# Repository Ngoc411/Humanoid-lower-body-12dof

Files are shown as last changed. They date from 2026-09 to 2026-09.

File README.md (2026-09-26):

<div align="center">
  
  <br>
  <em>Chaos — a 12-DoF humanoid lower-body robot, sim-to-real RL locomotion</em>
</div>

# Humanoid-lower-body-12dof (Chaos)

This repository holds the full stack for **Chaos**, a 12-degree-of-freedom humanoid
lower-body robot (6 DoF per leg: hip yaw / hip roll / hip pitch / knee / ankle pitch /
ankle roll): reinforcement-learning training in simulation, the ONNX policy runtime,
and the embedded firmware that runs on the physical robot.

> **Acknowledgement / reference:** the simulation and RL training pipeline in this
> repo is built on top of, and takes reference from,
> **[VinRobotics/vinrobotics_mjlab](https://github.com/VinRobotics/vinrobotics_mjlab)**.
> Credit to that project and its authors for the base framework this work extends.

## Project layout

```
.
├── source/Vin_Rsl_Rl/          # Isaac Lab-style RL extension (Python package "Vin_Rsl_Rl")
│   └── Vin_Rsl_Rl/
│       ├── assets/robots/      # Robot articulation config ("chaos.py": joints, actuators, PD gains)
│       └── tasks/              # Gym-style task definitions (manager-based & direct)
│           ├── manager_based/vin_rsl_rl/   # MDP: rewards, terminations, curriculum, observations
│           └── direct/                     # Direct-workflow + multi-agent (MARL) variants
├── scripts/                    # Train / play entry points for each RL library
│   ├── rsl_rl/                 # train.py, play.py, plot_policy_data.py (primary pipeline)
│   ├── rl_games/                # train.py, play.py
│   ├── sb3/                    # train.py, play.py
│   └── skrl/                    # train.py, play.py
├── step_response_data/         # Real-motor step-response / wave-motion logs used to fit
│                                # simulated actuator dynamics (armature, friction, viscous
│                                # friction) per joint against the physical robot
├── ws1_cpp/ws1_cpp/             # ROS 2 C++ workspace that runs on the Jetson (deploys the
│   ├── sensor_node/             #   trained ONNX policy on hardware)
│   ├── src/                     # sensor_node : SPI master, reads 46-float obs frame from STM32
│   ├── action_node/             # main_node   : runs actor.onnx, fall/recovery state machine
│   └── test_model_node/         # action_node : writes the 12-joint action frame back to STM32
│                                 # test_model_node : offline CLI sanity check of the ONNX model
├── Chaos_main_1/                # STM32F407VET6 firmware — main board / SPI slave to the
│                                 # Jetson, CAN master to the 12 per-joint motor nodes
│   ├── NODE_FLOW.md             # Full node/data-flow reference for the STM↔Jetson link
│   ├── JETSON_NOTES.txt         # Fall-detection & recovery handshake, data-safety checklist
│   └── STM32_SAFETY_SUMMARY.txt # NaN/CRC/framing/watchdog protections on the STM32 side
├── Chaos_test3/                  # STM32G474 firmware flashed to each of the 12 joint nodes
│                                 # (one CAN node per motor; NODE_ID selects which joint)
├── Hardware/                      # Mechanical CAD (SolidWorks) for the physical robot
│   ├── hip_2/hip_3/hip_connector, knee_1/2_left/right, ankle*  # Structural leg parts
│   ├── gearbox/                   # Custom planetary gearboxes for the BLDC actuators
│   │   ├── gearbox_5210/          #   (5210-size motor)
│   │   └── gearbox_3508/, gearbox_3508_2/  # (3508-size motor, two revisions)
│   ├── BLDC/                      # Motor mount parts for the 5210 / 3508 / 4108 BLDC motors
│   ├── bearing/                   # Bearing mounts
│   ├── assem_symplified.SLDASM    # Full simplified leg/body assembly
│   └── Jetson Nano.step           # Reference model for mounting the onboard computer
├── test7.usd                      # Isaac Sim USD asset for Chaos, referenced as
│                                  # `usd_path` in `source/.../assets/robots/chaos.py`
└── flat_ter.gif / flat_ter.mov   # Walking demo captured from simulation
```

## System overview

Chaos is trained to walk in simulation and deployed on hardware through a three-tier
control stack:

```
STM32F407 (main board)  ──CAN──►  12× STM32G474 joint nodes (motor control)
        ▲  │
       SPI │  46-float frames, 50 Hz
        │  ▼
  Jetson Orin Nano  ──►  ONNX policy (actor.onnx)  ──►  action back to STM32
```

1. **Training (simulation).** `source/Vin_Rsl_Rl` defines the Chaos robot (joint
   limits, PD gains, actuator dynamics) and locomotion task as an Isaac
   Lab-style extension. Actuator parameters (armature, friction, viscous
   friction per joint) were fit against real step-response and wave-motion
   data recorded from the physical motors (`step_response_data/`) so the
   simulated dynamics track the real robot.
2. **Policy export.** A trained policy is exported to `actor.onnx` for
   deployment.
3. **On-robot inference (Jetson).** The `ws1_cpp` ROS 2 workspace runs three
   nodes: `sensor_node` (SPI master, pulls the 46-float observation frame from
   the STM32 and converts deg/RPM → rad/rad·s⁻¹), `main_node` (runs the ONNX
   policy, owns the INIT → RUNNING → FALLEN state machine and fall/recovery
   logic, applies ankle linkage math and safety clamps), and `action_node`
   (converts the 12 joint commands back to degrees and writes them to the
   STM32). See `Chaos_main_1/NODE_FLOW.md` for the full frame layout and
   state-machine reference.
4. **Embedded control (STM32).** `Chaos_main_1` is the main board: it bridges
   the Jetson (SPI slave) and the 12 joint nodes (CAN master), and is
   responsible for the WAIT/READY handshake, fault handling, and deciding
   whether an action is safe to forward. `Chaos_test3` is the firmware flashed
   to each of the 12 individual joint/motor nodes, one per joint, selected by
   `NODE_ID` at flash time.

<div align="center">
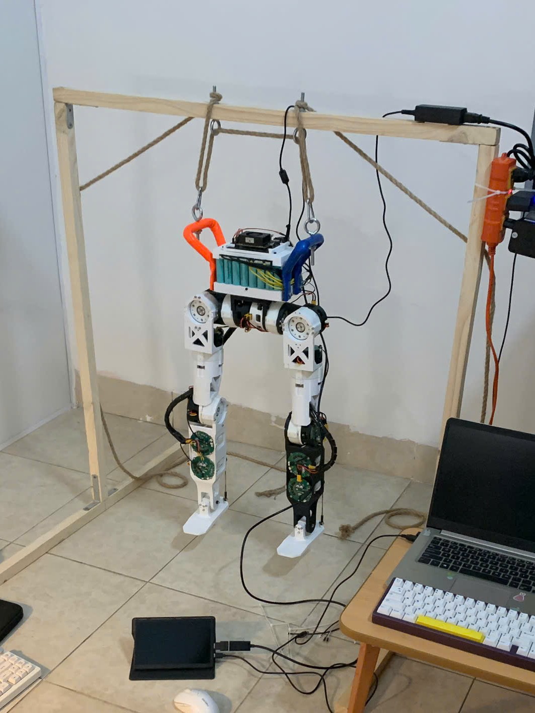
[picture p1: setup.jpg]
  
  <br>
  <em>Physical test rig: Chaos suspended from a tether frame while the RL
  policy runs live on the Jetson (foreground), so early policies can be
  tested on hardware without risking a fall.</em>
</div>

## Getting started

### Prerequisites

The `source/Vin_Rsl_Rl` package is an [Isaac Lab](https://isaac-sim.github.io/IsaacLab/)
extension, which itself runs on top of
[NVIDIA Isaac Sim](https://developer.nvidia.com/isaac/sim). Install both before
using this repo:

- **Isaac Sim** — see the
  [Isaac Sim installation guide](https://docs.isaacsim.omniverse.nvidia.com/latest/installation/index.html).
  This project was developed against Isaac Sim 4.5 / 5.0 / 5.1.
- **Isaac Lab** — see the
  [Isaac Lab installation guide](https://isaac-sim.github.io/IsaacLab/main/source/setup/installation/index.html)
  ([GitHub](https://github.com/isaac-sim/IsaacLab)). `source/Vin_Rsl_Rl` follows
  the standard Isaac Lab extension template, so it installs the same way as
  any other external Isaac Lab task extension.

### Simulation / RL training

```bash
# from the repo root, with an Isaac Lab environment set up
python -m pip install -e source/Vin_Rsl_Rl

# train with RSL-RL (the primary pipeline used for this robot)
python scripts/rsl_rl/train.py --task <task-name>

# play back a trained checkpoint
python scripts/rsl_rl/play.py --task <task-name> --checkpoint <path-to-checkpoint>
```

A trained checkpoint is already included under `logs/rsl_rl/`, so you can skip
training and watch the policy walk right away:

```bash
python scripts/rsl_rl/play.py \
  --task Template-Vin-Rsl-Rl-Flat-Play-v0 \
  --checkpoint logs/rsl_rl/2026-07-04_21-39-15/model_14000.pt
```

The exported ONNX/TorchScript versions of that same policy (used on the real
robot) are already available at
`logs/rsl_rl/2026-07-04_21-39-15/exported/{policy.onnx,policy.pt}` — no export
step needed.

> **Robot USD asset:** `chaos.py` currently points `usd_path` at a local
> development path (`D:/IsaacSim/test7.usd`). The actual asset is checked into
> this repo at `test7.usd`; update `usd_path` in
> `source/Vin_Rsl_Rl/Vin_Rsl_Rl/assets/robots/chaos.py` to point at your local
> copy of that file (or move/symlink it into your Isaac Sim assets folder)
> before running training or play.

Equivalent `train.py` / `play.py` entry points are also provided for
`rl_games`, `sb3`, and `skrl` under `scripts/`.

### Hardware deployment

The `ws1_cpp` workspace is a ROS 2 package intended to run on the Jetson Orin
Nano that is connected to the STM32F407 main board over SPI:

```bash
cd ws1_cpp/ws1_cpp
colcon build
source install/setup.bash
ros2 launch <package> <launch-file>   # or run sensor_node / main_node / action_node individually
```

`main_node` loads `actor.onnx` via ONNX Runtime; place the exported policy
where the node expects it before launching. `test_model_node` can be used to
sanity-check a model offline without any ROS 2 topics or SPI hardware:

```bash
ros2 run ws1_cpp test_model_node <45 space-separated observation floats>
```

### Firmware

`Chaos_main_1` and `Chaos_test3` are STM32CubeIDE projects (`.ioc` files
included). Open each in STM32CubeIDE to build and flash:
- **`Chaos_main_1`** → STM32F407VET6, the main/SPI-slave board. Bridges the
  Jetson (SPI3, DMA, 46-float / 184-byte frames each direction, triggered at
  50 Hz by the Jetson) and the 12 joint nodes over CAN. It polls all 12 nodes
  for feedback, forwards actions only when the system is armed and safe, and
  owns the fall-detection broadcast (CAN ID `150`) that puts every joint node
  into a homing state.
- **`Chaos_test3`** → STM32G474RETx, flashed once per joint node with a
  unique `NODE_ID` (1–12); all of that node's CAN IDs (command, feedback,
  init-done) are derived from `NODE_ID`. Each node runs its own motor control
  loop and reports position/velocity feedback back to the main board.

Both boards share a protection library (`lib/Protection` in `Chaos_main_1`)
covering NaN/Inf checks, clamping, CRC32 framing, sequence checks, a
watchdog, and slew-rate limiting — see `STM32_SAFETY_SUMMARY.txt` for the
full breakdown of what's implemented on the STM32 side versus what's still
planned (e.g. CRC/sequence numbers are not yet enabled on the SPI link).

### Hardware (mechanical design)

`Hardware/` contains the SolidWorks source files for the physical robot: the
structural leg parts (hip, knee, ankle links and connectors), the custom
planetary gearboxes built for the 5210 / 3508 BLDC actuators, the BLDC motor
mounts, bearing mounts, a simplified full-assembly file
(`assem_symplified.SLDASM`), and a reference STEP model for mounting the
Jetson Nano. Open the `.SLDPRT` / `.SLDASM` files in SolidWorks (or import the
`.STEP` files into other CAD tools) to inspect or modify the design.

## Safety design

The STM32 ↔ Jetson link and the on-robot policy runtime include several
fail-safe layers, documented in detail in `Chaos_main_1/NODE_FLOW.md`,
`Chaos_main_1/JETSON_NOTES.txt`, and `Chaos_main_1/STM32_SAFETY_SUMMARY.txt`:

- **Fall detection & recovery handshake** — both the STM32 and the Jetson
  independently estimate tilt from IMU data; recovery requires both sides to
  agree the robot has fallen and later stood back up before motion resumes.
- **NaN/Inf handling** — observations are never clamped (to avoid feeding the
  policy false data), only checked for finite values; actions are checked for
  finite values *before* clamping, since clamping propagates NaNs.
- **Joint limit clamping** and a startup/init handshake that requires all 12
  joint nodes to report ready before any action is forwarded.
- **Link-loss watchdog** — a stale observation stream (e.g. SPI desync, cable
  fault) forces the robot into a safe "fallen/hold" state rather than acting on
  outdated data.

## Notes

- `chaos.py` still has a hardcoded `D:/IsaacSim/...` path for the fixed-base
  variant (`fixed_base.usd`, used only for actuator step-response
  identification); that file isn't included in this repo, so update or remove
  that reference if you don't need the fixed-base bench.
- Some in-code comments and internal docs are written in Vietnamese; the
  English summaries above and in this README cover the key behavior.

---

## Author

**Ngoc**

Embedded Systems · Motor Control · Robotics

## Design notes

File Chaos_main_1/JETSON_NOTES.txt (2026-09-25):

================================================================================
 GHI CHÚ CHO PHÍA JETSON (SPI MASTER + POLICY)
 Dự án: Chaos_main_1  —  STM32F407 (main board / SPI slave) <-> Jetson Orin Nano
 Cập nhật: 2026-06
================================================================================

Tài liệu này gồm 2 phần:
  A. Hành vi khi NGÃ (falling) mà Jetson PHẢI làm — đối ứng với STM.
  B. Các LỚP BẢO VỆ DATA nên/phải có ở Jetson.

Bối cảnh hệ thống (tóm tắt):
  - Robot 12 khớp. STM hỏi 12 node qua CAN, gom obs, gửi Jetson qua SPI.
  - Jetson chạy policy, trả action (lệnh vị trí khớp) qua SPI; STM forward xuống node.
  - Jetson TRIGGER vòng 50Hz LIÊN TỤC (tự đồng hồ). STM là bên quyết định
    CÓ forward action hay không.
  - ĐƠN VỊ: trên dây/STM là ĐỘ (deg) và RPM. rad / rad/s CHỈ dùng nội bộ Jetson.
    => Jetson tự quy đổi deg<->rad, RPM<->rad/s. (IMU angular velocity đã là rad/s.)
  - Hệ trục: z thẳng đứng, x đi tới (hệ chuẩn). Thẳng đứng = 90° so mặt đất.
  - KHUNG SPI = 46 float (184 byte) MỖI CHIỀU (đã đổi từ 45). Jetson PHẢI dùng
    đúng 46 float, nếu không SPI lệch khung (chưa có CRC). Trường mới:
        TX[45] = STATUS (STM->Jetson):  0.0 = WAIT (chưa sẵn sàng) ; 1.0 = READY.
    Các trường TX khác: [0-2]angvel(rad/s) [3-5]grav(norm) [6-8]cmd
        [9-20]joint pos(DEG) [21-32]joint vel(RPM) [33-44]prev action.
    RX[0]=2.0(CMD_ACTION), RX[1-12]=action(deg), [13-45] padding.

================================================================================
 A. HÀNH VI KHI NGÃ (FALLING)  — Jetson PHẢI làm
================================================================================

1) PHÁT HIỆN NGÃ (độc lập với STM)
   - Jetson tự có thuật toán xét góc nghiêng (từ IMU / projected gravity).
   - Quy ước giống STM: thẳng đứng = 90° so mặt đất; coi là NGÃ khi góc so mặt
     đất < ngưỡng (STM dùng 70°, tức nghiêng khỏi phương thẳng đứng > 20°).
     Nên dùng cùng ngưỡng để hai bên nhất quán.
   - Nên có chống nhiễu (phải nghiêng vài chu kỳ liên tiếp mới kết luận ngã),
     không kết luận từ 1 mẫu lẻ.

2) KHI XÁC ĐỊNH ĐÃ NGÃ
   - GIỮ obs sống: Jetson VẪN trigger 50Hz, VẪN pull SPI để đọc obs (gồm STATUS).
     CHỈ TẮT policy + action (không chạy model, không gửi action).
   - RESET toàn bộ data/state về 0:
       * buffer observation, lịch sử action (prev actions),
       * mọi trạng thái nội bộ của policy (hidden state / RNN nếu có),
       * bộ lọc, tích phân, normalizer running-stats tạm (nếu áp dụng).
   - Sau đó chỉ ĐỢI tín hiệu READY từ STM (TX[45]).
   - (STM song song: phát hiện ngã -> broadcast CAN 150 -> các node HOMING lại;
     STM "quay về dạng init", bật lại poll homing (TIM5), và đặt STATUS=WAIT.
     STM dừng forward action; obs vẫn gửi đều với STATUS=WAIT.)

3) ĐIỀU KIỆN ĐỂ CHẠY LẠI = NHẬN READY TỪ STM  (KHÓA CHÉO 2 LỚP)
   - STM chỉ đặt TX[45]=READY khi: các node HOMING XONG (đủ 12 init) VÀ robot
     đã ĐỨNG THẲNG ổn định.
   - Jetson chỉ coi READY là hợp lệ KHI CHÍNH NÓ cũng đã phát hiện ngã trước đó
     (cùng thuật toán nghiêng với STM). Tức:
        * Nếu Jetson đang ở trạng thái "đã ngã, đang đợi" + thấy STATUS=READY
          -> mới chuyển sang bước chạy lại.
        * READY đến mà Jetson KHÔNG nghĩ là đã ngã -> bỏ qua (chống tín hiệu lạ).
   - Đây là khóa chéo: cả hai phía phải đồng ý "đã ngã" và "đã hồi phục".

4) SAU KHI NHẬN READY -> CHỜ ỔN ĐỊNH 5s RỒI MỚI XUẤT ACTION
   - Khi đã hợp lệ READY: bắt đầu chạy model + xuất action.
   - Nên đợi data ổn định liên tục 5s (obs ít dao động, đầy đủ) rồi mới xuất,
     tránh hành động trên data quá độ ngay sau khi dậy.

5) PHỐI HỢP THỜI GIAN VỚI STM
   - STM cũng có cổng "ổn định 5s" (armed): chỉ forward action xuống node khi thấy
     RUN + obs đủ + action Jetson tươi + ÍT DAO ĐỘNG liên tục 5s.
   - STM đếm "action ổn định" dựa trên việc Jetson CÓ gửi action; Jetson lại đợi 5s
     của mình trước khi gửi => tổng từ lúc READY đến lúc robot nhận lệnh ~ 10 GIÂY
     (5s Jetson + 5s STM nối tiếp). RÚT NGẮN được (đổi STABILIZE_MS + mốc Jetson),
     phải đổi ĐỒNG BỘ.

   Sơ đồ (sau ngã):
     ngã -> Jetson tắt policy/action, reset, đợi READY ; STM gửi 150 + WAIT, poll homing
     node homing xong + đứng thẳng -> STM đặt STATUS=READY
     Jetson thấy READY (và nó cũng đã ngã) -> bắt đầu (đợi 5s ổn định) -> gửi action
     STM thấy obs+action ổn định 5s -> "armed" -> xả action xuống node -> chạy lại

6) TƯƠNG TỰ KHI INIT (khởi động)
   - Lúc mới bật: STM gửi obs với STATUS=WAIT tới khi đủ 12 node init + đứng thẳng,
     rồi mới READY. Jetson đợi READY mới chạy (init coi như không cần "đã ngã trước").
   - Sau READY cũng warmup 5s như trên trước khi STM xả action.

================================================================================
 B. CÁC LỚP BẢO VỆ DATA Ở JETSON
================================================================================

Triết lý:
  - ACTION (lệnh xuống motor): PHẢI chặn/kẹp — vì đi tới phần cứng.
  - OBS (data vào policy): phải TRUNG THỰC — KHÔNG kẹp (clamp) giá trị thật;
    chỉ chặn số rác (NaN/Inf). Kẹp obs = nói dối policy.
  - Khi nghi ngờ -> KHÔNG hành động (fail-safe), thay vì đoán.
  - "nếu data lỗi thì không gửi gì cả" (đã thống nhất) — đúng tinh thần fail-safe.

-------------------------------------------------------------------------------
 B.1  NHÓM PHẢI CÓ (must-have)
-------------------------------------------------------------------------------

[1] KIỂM KHUNG (framing) khi NHẬN obs từ STM
    - Nếu sau này thêm magic header/footer + length + CRC + sequence vào khung SPI:
      kiểm đủ các trường này. Sai -> bỏ khung, không xử lý.
    - Chống SPI desync/byte-slip (lệch byte -> toàn bộ float thành rác mà vẫn "đủ
      độ dài"). Đây là rủi ro lớn nhất của SPI.
    (Hiện khung CHƯA có CRC/seq; cần làm ĐỒNG BỘ cả hai phía STM + Jetson.)

[2] LỌC NaN/Inf TRÊN OBS — ĐẶT TRƯỚC normalize
    - np.isfinite / nan_to_num NGAY sau khi unpack, TRƯỚC khi chuẩn hóa.
    - Vì (x-mean)/std có thể tự đẻ NaN khi std≈0.
    - NaN lan truyền âm thầm trong NumPy/PyTorch -> 1 NaN obs = action NaN.

[3] LỌC NaN/Inf + CLAMP TRÊN ACTION — isfinite TRƯỚC clamp
    - Thứ tự bắt buộc: kiểm isfinite trước, clamp sau.
      (clamp(NaN) trả về NaN vì so sánh với NaN luôn False -> clamp KHÔNG chặn NaN.)
    - Clamp action về dải hợp lệ từng khớp trước khi gửi.

[4] ĐÓNG KHUNG GỬI ĐỐI XỨNG (khi đã thêm CRC/seq)
    - Jetson chèn + STM kiểm: header + sequence + CRC.
    - CRC32 phải TRÙNG chuẩn với STM. STM dùng CRC32 tương thích zlib
      (poly 0xEDB88320, init/xorout 0xFFFFFFFF). Python: zlib.crc32(data) & 0xFFFFFFFF.
      (Kiểm chéo: CRC32("123456789") == 0xCBF43926.)

[5] FAIL-SAFE: data lỗi -> KHÔNG gửi action
    - Khung obs hỏng / NaN / không hợp lệ -> KHÔNG chạy policy ra lệnh bừa.
      Hoặc không gửi gì (STM sẽ giữ tư thế), hoặc gửi lệnh giữ an toàn.
    - "Khi nghi ngờ thì đừng tác động."

[6] SEQUENCE / FRESHNESS + WATCHDOG
    - sequence để phát hiện khung lặp (stale), mất khung, sai thứ tự.
    - watchdog: nếu N chu kỳ không có obs hợp lệ -> coi như mất link -> fail-safe.
    - Data CŨ nguy hiểm hơn KHÔNG data (vì che giấu sự cố).

-------------------------------------------------------------------------------
 B.2  NHÓM NÊN CÓ (should-have)
-------------------------------------------------------------------------------

[7]  RANGE / PLAUSIBILITY trên OBS (chỉ để PHÁT HIỆN, KHÔNG kẹp)
     - Giá trị hữu hạn nhưng phi lý (vd pos 5000°, vel khổng lồ) -> đánh dấu/cảnh
       báo, có thể dùng làm tín hiệu vào fail-safe. NHƯNG giữ giá trị thật cho obs.

[8]  SLEW-RATE LIMIT trên ACTION
     - Giới hạn |action[t] - action[t-1]| để chặn spike đơn lẻ; làm mượt lệnh.

[9]  TIÊU THỤ VALIDITY / TRẠNG THÁI từ STM
     - Nếu STM gửi kèm bitmask khớp thiếu / cờ trạng thái -> policy biết khớp nào
       không đáng tin để giảm tin cậy / giữ an toàn. (Cần mở rộng khung — làm sau.)

[10] RETRY KHI CRC FAIL (đặc quyền của master)
     - STM (slave) không yêu cầu truyền lại được; chỉ Jetson (master) làm được.
       Obs CRC sai -> Jetson chủ động khởi tạo lại transaction.

[11] BỘ ĐẾM / LOG LỖI
     - Đếm crc_err, framing_err, seq_gap, nan_count, clip_count, stale_count...
     - Lỗi gián đoạn (vài lần/giờ) chỉ thấy qua thống kê dài hạn.

[12] CẤU HÌNH TRUYỀN DẪN BẢO THỦ + GUARD KHỞI ĐỘNG
     - Chọn SPI clock thấp/ổn định (đo thực tế, lùi biên an toàn).
     - CS sạch, mỗi transaction trọn vẹn (STM là slave NSS_HARD_INPUT -> cạnh CS
       chính là ranh giới khung; CS bẩn -> desync).
     - Bỏ qua vài khung đầu sau khi mở SPI (buffer chưa ổn định).

-------------------------------------------------------------------------------
 B.3  THỨ TỰ ÁP DỤNG ĐÚNG (khi nhận obs)
-------------------------------------------------------------------------------
     1. framing (magic/length)      -> sai: bỏ khung
     2. CRC                         -> sai: bỏ khung (+ retry)
     3. sequence                    -> lặp/sai thứ tự: bỏ
     4. isfinite obs (NaN/Inf)      -> thay/loại số rác (TRƯỚC normalize)
     5. (range chỉ để phát hiện, KHÔNG kẹp obs)
     6. normalize -> policy
     7. isfinite action -> clamp action -> (slew) -> đóng khung + CRC -> gửi
     8. mọi bước: cập nhật bộ đếm lỗi

================================================================================
 GHI CHÚ KẾT
================================================================================
  - Mọi thay đổi liên quan tới KHUNG SPI (CRC/sequence/validity/đơn vị) phải làm
    ĐỒNG BỘ cả STM lẫn Jetson, nếu không sẽ lệch và hỏng giao tiếp.
  - Hai bên dùng CHUNG quy ước góc nghiêng/ngã và CHUNG mốc thời gian ổn định 5s.
  - CAN ID tham chiếu (phía STM <-> node):
        50      SYNC (STM->node)
        51..62  action từng khớp (STM->node)
        1..12   feedback (node->STM)
        100     hỏi init xong chưa (STM->node)
        101..112 báo init xong (node->STM)
        150     FALLING — báo ngã (STM->node, node tự vào trạng thái falling)
================================================================================

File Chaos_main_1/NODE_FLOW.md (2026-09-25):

# ws1_cpp — Node Flow Reference

Robot: **STM32F407 (SPI slave) ↔ Jetson Orin Nano (SPI master + RL policy)**.
Per `JETSON_NOTES.txt`. Units on the wire are **deg / RPM**; rad / rad/s are
Jetson-internal only. SPI frame = **46 floats (184 bytes) each direction**.

```
            sensor_45_float (46 floats)            main/output (12 floats)
 STM ──SPI──►  sensor_node  ──────────────►  main_node  ──────────────►  action_node  ──SPI──► STM
 (obs+STATUS)                (obs converted)            (action, rad)                  (action, deg)
```

Three independent nodes, two separate SPI transactions on `/dev/spidev0.0`
(sensor reads obs; action writes commands).

---

## Frame layouts

### Obs frame — STM → Jetson (read by sensor_node), 46 floats
| idx | field | unit on wire | Jetson converts to |
|-----|---|---|---|
| 0–2 | base angular velocity | rad/s | (unchanged) |
| 3–5 | projected gravity (normalized) | – | (unchanged) |
| 6–8 | velocity commands | – | (unchanged) |
| 9–20  | joint position (12) | deg | rad |
| 21–32 | joint velocity (12) | RPM | rad/s |
| 33–44 | prev action (12) | deg | rad |
| **45** | **STATUS** | 0=WAIT, 1=READY | published raw |

### Action frame — Jetson → STM (written by action_node), 46 floats
| idx | field |
|-----|---|
| 0 | 2.0  (CMD_ACTION marker) |
| 1–12  | 12 joint commands (deg) |
| 13–45 | padding (0.0) |

---

## 1. sensor_node  (`sensor_node/sensor_node.cpp`)

**Role:** SPI master. Triggers the STM at a fixed rate, reads the 46-float obs
frame, converts units, publishes it. Build-time `TEST` macro selects mode
(`0` = production, `1` = GPIO+SPI bench, `2` = SPI loopback). Production is `#else`.

**GPIO lines**
- Pin 15 (line 85): OUTPUT — trigger pulse.
- Pin 7  (line 144): INPUT — EXTI rising edge from STM ("data ready").

**Startup**
1. `openSPI()` — open `/dev/spidev0.0`, set mode 0, 8-bit, 1 MHz.
2. `openGPIO()` — request pin 15 output + pin 7 rising-edge events; launch
   `gpioWatchThread`.
3. Create publisher `sensor_45_float` and a **100 Hz wall timer** → `timerCallback`.

**Trigger loop — `timerCallback` (every 10 ms)**
- If no SPI transfer is in progress, **toggle pin 15** (H→L→H→L…), recording the
  timestamp only on the HIGH edge. Net result = 50 Hz square wave; each rising
  edge is the trigger the STM waits on.

**EXTI loop — `gpioWatchThread` (separate thread)**
1. Block on `gpiod_line_event_wait(pin7)`.
2. On rising edge: log dt between edges + latency from pin-15 HIGH.
3. Set `transfer_in_progress_`, force pin 15 LOW, sync `pulse_state_`.
4. `doSPITransfer()`, then clear `transfer_in_progress_`.

**`doSPITransfer`**
1. Full-duplex `SPI_IOC_MESSAGE` of `rx_len_` (46×4 = 184 B). TX is don't-care.
2. `memcpy` rx → 46 floats.
3. Convert in place: `[9-20]` deg→rad, `[21-32]` RPM→rad/s, `[33-44]` deg→rad.
   `[45]` STATUS left raw.
4. Publish all 46 floats on `sensor_45_float`.

---

## 2. main_node  (`src/main.cpp`, `src/main.hpp`)

**Role:** the brain. Subscribes obs, runs the ONNX policy, applies linkage math +
safety, and owns the **fall / READY state machine**. Publishes 12 action
floats (rad) on `main/output`. `TEST 0` here = a standalone linkage unit-test node;
`#else` (active) = `MainNode`.

**Startup (`MainNode()`)**
1. Init ONNX Runtime, load `actor.onnx` (single-thread).
2. Fetch I/O names; pre-allocate 45-in / 12-out buffers.
3. Subscribe `sensor_45_float`; publish `main/output`.
4. Start a **10 Hz watchdog** timer → `watchdogTick`. Initial state = `INIT`.

**Per-message — `sensorDataCallback`**
1. **Framing:** require exactly 46 floats. Split `obs = [0..44]`, `status = [45]`.
2. **Obs fail-safe:** any non-finite obs → `nan_obs_count_++`, drop frame, return.
3. Stamp `last_valid_obs_` (feeds watchdog).
4. **State machine** — 3 states, `INIT → RUNNING → FALLEN → INIT`. The 5 s warmup
   lives on the **STM32**, not the Jetson. STATUS is consulted **only in INIT**.

```
INIT      status==READY ──────────────────────────► RUNNING (reset fall debounce)
          (else: stay, no action out)

RUNNING   detectFall() true ──► resetPolicyState() ► FALLEN
          else ──────────────────────────────────► runInference()  (publishes)
          (STATUS is IGNORED here — only a fall leaves RUNNING)

FALLEN    detectStanding() true ──────────────────► INIT  (await READY again)
          (model off, prev_action/filter zeroed; only standing detection runs)
```

   - **Fall** (`detectFall`, RUNNING): `tilt = atan2(hypot(gx,gy), -gz) > 20°` for
     **3 consecutive** cycles.
   - **Standing** (`detectStanding`, FALLEN): same tilt back **< 20°** for 3
     consecutive cycles. Obs keeps flowing during a fall, so this works while the
     robot is being re-homed.
   - Recovery needs **both** signals, split across states: Jetson sees the robot
     stand up (`FALLEN→INIT`), then the STM declares `READY` (`INIT→RUNNING`).
   - Only `RUNNING` ever calls `runInference` / publishes. INIT & FALLEN are silent
     (STM holds the last safe pose).

**`runInference` (RUNNING only)**
1. CSV session logging: when `obs[6,7,8]` (commands) go non-zero, open a new
   `logs/session_NNN.csv`; on all-zero, close it. (Only active while RUNNING.)
2. Copy first 45 obs into the model buffer.
3. **Pre-model:** inverse-linkage the two ankle pairs (motor θ_D/θ_C → rot_x/rot_y)
   for position + velocity; overwrite `obs[33-44]` with last cycle's raw action;
   subtract pose offset.
4. **Run ONNX** → 12 raw outputs.
5. **Action fail-safe:** any non-finite output → `nan_action_count_++`, return
   (checked **before** clamp, since `clamp(NaN)=NaN`).
6. **Post-model:** `out·SCALE + poseOffset`, clip to per-joint limits
   (count clips), store raw as next-cycle prev_action, optional EMA low-pass.
7. **Forward linkage** on ankle pairs (rot_x/rot_y → θ_D/θ_C).
8. Publish 12 floats (rad) on `main/output`; append CSV row.

**`watchdogTick` (10 Hz, runs independently of obs messages)**
- Every valid obs stamps `last_valid_obs_`. The watchdog checks the gap since then.
- If RUNNING and no valid obs for **>200 ms** (obs stream died — cable, STM crash,
  SPI desync) → `stale_count_++`, `resetPolicyState()`, → FALLEN. When obs stops,
  the message callback also stops, so this timer is the only thing that can still
  react and keep the robot from acting on a dead link.
- Every ~5 s log `[STATS] nan_obs / nan_action / clip / stale / state`.

**`detectFall` / `detectStanding` / `resetPolicyState`**
- `detectFall` (RUNNING): debounced `tilt > 20°`. `detectStanding` (FALLEN):
  debounced `tilt < 20°`. ⚠️ Both assume `gz≈-1` upright — verify against logged
  obs[3-5]; flip `-gz` in both if your convention reads `+1`.
- `resetPolicyState`: zero prev_action + filter state + both debounce counters,
  close any open log.

---

## 3. action_node  (`action_node/action_node.cpp`, `.hpp`)

**Role:** SPI master for the command direction. Subscribes the policy output and
writes a 46-float action frame to the STM.

**Startup:** open `/dev/spidev0.0` (mode 0, 8-bit, 1 MHz); subscribe `main/output`.

**Per-message — `commandCallback`**
1. Require exactly 12 floats.
2. **Fail-safe:** any non-finite command → log + **do not send**.
3. Convert rad → deg.
4. Build 46-float frame: `[0]=2.0`, `[1-12]=cmd°`, `[13-45]=0`.
5. `sendSPI` — TX-only `SPI_IOC_MESSAGE` (184 B).

---

## 4. test_model_node  (`test_model_node/test_model_node.cpp`)

**Role:** offline CLI sanity check of the ONNX model — no ROS spin, no SPI.

**Flow:** parse 45 floats from argv → load `actor.onnx` → single inference →
print the 12 raw outputs space-separated → exit.

```bash
ros2 run ws1_cpp test_model_node 0.0 0.0 ... (45 numbers)
```

---

## State / safety summary

| Concern | Where | Behavior |
|---|---|---|
| WAIT/READY handshake | main_node INIT only | RUNNING starts on STM READY; 5 s warmup is on the STM |
| Fall detection | main_node `detectFall` (RUNNING) | tilt >20°, debounce 3 → FALLEN |
| Recovery | main_node FALLEN→INIT→RUNNING | Jetson sees standing (→INIT), then STM READY (→RUNNING) |
| Obs corruption | main_node | non-finite → drop frame |
| Action corruption | main_node + action_node | non-finite → don't publish/send |
| Joint limits | main_node | clip + count |
| Link loss | main_node watchdog | stale >200 ms → FALLEN |
| Unit conversion | sensor (in) / action (out) | deg↔rad, RPM→rad/s |

**Not yet implemented** (needs matching STM work, per spec): CRC32, sequence
numbers, magic-header framing.
```

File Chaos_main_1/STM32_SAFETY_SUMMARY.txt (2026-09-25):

================================================================================
 TÓM TẮT AN TOÀN / BẢO VỆ DATA — PHÍA STM32 (main board, SPI slave)
 Dự án: Chaos_main_1  —  STM32F407VET6
 Cập nhật: 2026-06
================================================================================

Vai trò STM32: cầu nối Jetson <-> 12 node motor.
  - CAN: hỏi 12 node (SYNC) -> gom obs (pos/vel); nhận action -> forward node.
  - SPI3 (slave, DMA): gửi obs (46 float) lên Jetson, nhận action (46 float) về.
  - Jetson trigger vòng 50Hz LIÊN TỤC; STM là bên QUYẾT ĐỊNH có forward action không.
  - ĐƠN VỊ tại STM/dây: ĐỘ (deg) + RPM. (rad/rad-s chỉ ở Jetson.)
  - Hệ trục: gz = trục thẳng đứng. Đứng thẳng = gz ≈ -1.

================================================================================
 1) THƯ VIỆN PROTECTION  (lib/Protection)
================================================================================
  Độc lập HAL, test được trên PC. Cung cấp:
    - NaN/Inf:     Protection_IsFinite, ArrayAllFinite
    - Range/clamp: Protection_Clamp, InRange, Sanitize
    - CRC32:       Protection_CRC32 (tương thích zlib; "123456789"->0xCBF43926),
                   AppendCRC32, CheckTrailingCRC32
    - Framing:     CheckMagic/WriteMagic
    - Sequence:    SeqCheck (FIRST/OK/GAP/DUP/OUT_OF_ORDER)
    - Watchdog:    WatchdogInit/Feed/Expired (an toàn khi tick tràn 32-bit)
    - Slew:        SlewInit/SlewStep/ApplyActionSlew
    - Validator:   ValidateActions (NaN+clamp+hold), ValidateJoint (hiện không dùng)
    - Giới hạn vị trí TỪNG khớp (deg) lấy từ Chaos_test3 SP_LIMIT:
        j0[-50,50] j1[-50,50] j2[-15,10] j3[-10,15] j4[-10,10] j5[-10,10]
        j6[-100,0] j7[-100,0] j8..j11[-45,45]
      Vận tốc: |v| <= PROT_JOINT_VEL_ABS_MAX (RPM, tạm 30 — đo lại thực tế).

================================================================================
 2) LỌC DATA QUA CAN / SPI
================================================================================
  A. ACTION (Jetson -> node) — trong ProcessSpiFrame, PHẢI chặn/kẹp:
       - check frame type == CMD_ACTION  (spi_rx_buffer[0] == 2.0f)
       - NaN/Inf  -> giữ lệnh hợp lệ trước đó (hold prev_actions), KHÔNG về 0
       - clamp về dải vị trí TỪNG khớp (deg)
       - slew 4c: ĐANG TẮT (PROT_ENABLE_ACTION_SLEW=0) — bật sau khi đo biên độ
       - chỉ forward khi SafeLevel==RUN + đã "armed" (xem mục 6, 7)

  B. OBS — phải TRUNG THỰC, KHÔNG clamp (kẹp obs = nói dối policy):
       - feedback khớp (CAN RX): NaN -> giữ giá trị cũ; ngoài tầm -> GIỮ số thật,
         chỉ ĐẾM (can_pos_bad/can_vel_bad).
       - IMU/cmd (PublishObsToSpi, obs_finite): NaN -> 0 (đếm obs_nan); KHÔNG clamp.

  C. CHƯA làm (cần ĐỒNG BỘ với Jetson): magic header/footer + sequence + CRC32
     trên khung SPI. Hiện chỉ có "frame type" tối thiểu.

================================================================================
 3) HANDSHAKE INIT (chờ đủ 12 node mới chạy)
================================================================================
  - TIM5 (5s) broadcast CAN_ID_CHECK_INIT_DONE (100) hỏi "init xong chưa".
  - Node báo xong bằng CAN_ID_INIT_DONE = 101..112 (mỗi node 1 ID).
  - STM gom bit vào init_done_mask; đủ 12 (0x0FFF) -> all_nodes_ready=1, STOP TIM5.
  - Trước khi đủ: chu kỳ obs VẪN chạy (đọc IMU, gửi STATUS=WAIT) nhưng action bị
    chặn bởi SafeLevel (HOLD khi !all_nodes_ready).
  - Bền với mất gói / đua thứ tự boot (cứ 5s hỏi lại).

================================================================================
 4) CHÍNH SÁCH THIẾU KHỚP (obs)  — mỗi vòng đếm số khớp thiếu
================================================================================
    thiếu 0..3 (<=OBS_MAX_MISSING)  : gửi obs (khớp thiếu xài số cũ).
    thiếu 4+ lẻ tẻ                  : KHÔNG gửi obs vòng đó -> PD5 thấp -> motor tự giữ.
    thiếu 4+ 4 vòng liền            : obs_locked=1 -> HOLD (bỏ lệnh, đứng yên).
    đang khóa, đủ 5 vòng tốt liền   : mở khóa.
    thiếu 4+ >=250 vòng liền (~5s)  : reset hoàn toàn về init (init_done_mask=0,
                                       all_nodes_ready=0, obs_locked=0, bật lại TIM5).
  Chính sách trên CHỈ áp dụng ở PHA SẴN SÀNG (all_nodes_ready=1 && !robot_falling).
  Ở PHA CHƯA SẴN SÀNG: LUÔN gửi obs với STATUS=WAIT, không áp khóa/arming.
  Không cắt FET ở bất kỳ nhánh nào.
  Tham số: OBS_MAX_MISSING=3, OBS_SEVERE_ENTER=4, OBS_RECOVER_GOOD=5,
           OBS_REINIT_CYCLES=250.

================================================================================
 5) PHÁT HIỆN NGÃ (falling)  — từ projected gravity, sign-aware
================================================================================
  - KHỚP công thức Jetson: tilt = atan2(hypot(gx,gy), -gz) > 20°
    Tương đương (sign-aware, dùng gz CÓ DẤU):
        gz >= 0                          -> ngã chắc chắn (lật ngửa / lật úp)
        gz <  0  VÀ  h² > gz² * 0.13247 -> ngã (h=hypot(gx,gy), 0.13247=tan²(20°))
    LƯU Ý: đứng thẳng gz ≈ -1; gz>=0 là dấu hiệu lật — dùng gz² sẽ bỏ sót trường hợp này.

  - Chống nhiễu: nghiêng FALL_ENTER_CYCLES(3) vòng liền -> robot_falling=1.
                 thẳng lại FALL_EXIT_CYCLES(10) vòng liền -> robot_falling=0.

  - Khi ngã (cạnh lên robot_falling 0->1):
        * reset all_nodes_ready=0, init_done_mask=0, action_armed=0.
        * broadcast CAN 150 theo CỤM (FALLING_BURST_CYCLES=10 vòng, KHÔNG liên tục)
          -> node nhận -> tự NVIC_SystemReset -> chạy lại calibration+homing.
          (gửi cụm thay vì liên tục để node KHÔNG reset lặp khi robot còn nằm.)
        * bật lại TIM5 -> poll CHECK_INIT_DONE (homing xong chưa).

  - Chu kỳ obs VẪN chạy (Jetson giữ trigger 50Hz) -> đọc IMU phát hiện đứng thẳng,
    gửi obs cho Jetson với STATUS=WAIT.

  - Hồi phục: robot_falling=0 (10 vòng thẳng) VÀ đủ 12 node init xong
    -> STATUS=READY -> Jetson chạy lại -> STM arming 5s -> xả action.

  - IMU NaN -> giữ nguyên trạng thái (không cập nhật streak, không kết luận).
  - LƯU Ý: giả định gz là trục thẳng đứng — kiểm lúc đứng yên gz≈-1.

================================================================================
 6) TRẠNG THÁI AN TOÀN THỐNG NHẤT  (Robot_SafeLevel)
================================================================================
  Lấy mức nguy hiểm NHẤT từ mọi nguồn (thứ tự ưu tiên):
        robot_falling=1                        -> SAFE_PROTECT
        !all_nodes_ready / obs_locked          -> SAFE_HOLD
        can_busoff=1                           -> SAFE_HOLD
        còn lại                                -> SAFE_RUN
  (SAFE_SHUTDOWN để dành cho BMS — chưa làm.)

  Bus-off: vào HOLD; tự xóa can_busoff khi nhận lại được frame CAN bất kỳ.

  ProcessSpiFrame kiểm tra: SafeLevel != SAFE_RUN -> return (không forward).
  Arming (mục 7) kiểm tra thêm: SafeLevel == SAFE_RUN mới tính thời gian ổn định.

================================================================================
 7) CỔNG ỔN ĐỊNH 5s (arming)  — sau init / sau khi đứng dậy
================================================================================
  STM chỉ forward action khi: action_armed=1.
  Arming đạt được khi TẤT CẢ điều kiện sau giữ LIÊN TỤC đủ STABILIZE_MS (5000ms):
    - SafeLevel == SAFE_RUN
    - thiếu khớp <= OBS_MAX_MISSING (obs đủ)
    - action từ Jetson "tươi" (watchdog 60ms chưa expire)
    - mọi khớp đổi < STABLE_DELTA_DEG (1°) so vòng trước (ít dao động)
    - nrf_action=1 (NRF gate cho phép — bật/tắt qua remote)
  Một trong các điều kiện fail -> đồng hồ reset về 0 (đếm lại từ đầu).
  Một khi armed: giữ nguyên cho đến khi ngã / mất node / reset.

  Tín hiệu cho Jetson: TX[45] STATUS = READY khi (all_nodes_ready=1 && !robot_falling),
                        else WAIT.  Arming ở STM diễn ra SAU khi Jetson thấy READY.

  Cổng cuối cùng:  forward action  <=>  SafeLevel==RUN  VÀ  action_armed==1

  KHUNG SPI: 46 float (184 byte) — TX[45]=STATUS. JETSON PHẢI dùng 46 float.

================================================================================
 8) WATCHDOG LINK ACTION (Lớp 5)
================================================================================
  - Feed mỗi khung action hợp lệ (CMD_ACTION, kể cả khi chưa armed). Quá
    PROT_ACTION_TIMEOUT_MS(60ms) không có -> watchdog expire; arming reset.
  - Mất link -> motor giữ lệnh cuối (không có khung mới -> không forward).

  Ngoài ra: SPI_TIMEOUT_MS (1000ms) — nếu Jetson KHÔNG clock SPI hoàn toàn quá
  1000ms, STM reset về trạng thái WAIT + trigger homing lại (kiểm tra trong main loop
  qua spi_last_ms).

================================================================================
 9) QUAN TRẮC (đọc trong debugger)  — prot_stats + biến trạng thái
================================================================================
  prot_stats: action_nan, action_clip, action_slew, can_pos_bad, can_vel_bad,
              obs_nan, stale_events, (spi_crc/seq... khi làm CRC).
  Trạng thái: Robot_SafeLevel(), action_armed, robot_falling, obs_locked,
              obs_bad_streak/good_streak, obs_severe_count, last_severe_joints,
              all_nodes_ready, init_done_mask, can_busoff,
              collecting_timeout_count, last_timeout_joints,
              dbg_action_full_sent, dbg_action_tx_timeout,
              jetson_action_link_ok, dbg_action_timeout_ms.

================================================================================
 10) CAN ID  /  TIMER
================================================================================
  CAN ID:
     50       SYNC (STM->node)
     51..62   action từng khớp (STM->node)  [CAN_ACTION_ID_BASE=0x33]
     1..12    feedback pos/vel (node->STM)
     100      CHECK_INIT_DONE (STM->node)
     101..112 INIT_DONE (node->STM)
     150      FALLING (STM->node)

  TIMER (TIM2/3/4/5 trên APB1 = 84MHz):
     TIM2  1kHz(1ms)  watchdog PD5 (trigger 10ms — force PD5 LOW nếu SPI T1 chậm)
     TIM3  1kHz(1ms)  cycle timer: abort action@5ms, collecting timeout@10ms
     TIM4  1kHz(1ms)  EXTI gate (15ms — chặn glitch / re-trigger)
     TIM5  0.2Hz(5s)  poll CHECK_INIT_DONE (dừng khi đủ 12 node)

================================================================================
 11) THAM SỐ CHỈNH ĐƯỢC  (lib/Utils/utils.h)
================================================================================
  COLLECTING_TIMEOUT_MS=10  | OBS_MAX_MISSING=3   | OBS_SEVERE_ENTER=4  |
  OBS_RECOVER_GOOD=5        | OBS_REINIT_CYCLES=250|
  FALL_GROUND_ANGLE_DEG=70  | FALL_TILT_TAN2=0.13247 (=tan²(20°); đổi góc->đổi số này) |
  FALL_ENTER_CYCLES=3       | FALL_EXIT_CYCLES=10  | FALLING_BURST_CYCLES=10 |
  STABILIZE_MS=5000         | STABLE_DELTA_DEG=1.0 |
  PROT_ACTION_TIMEOUT_MS=60 | SPI_TIMEOUT_MS=1000  |
  PROT_ENABLE_ACTION_SLEW=0 | PROT_ACTION_SLEW_MAX=5
  (lib/Protection/protection.h: PROT_JOINT_POS_MIN/MAX[12], PROT_JOINT_VEL_ABS_MAX)

================================================================================
 12) CHƯA LÀM / CÒN LẠI
================================================================================
  - !!! JETSON phải dùng khung SPI 46 float (184 byte) — STM đã đổi xong.
  - SPI framing đầy đủ: magic + sequence + CRC32 (cần đồng bộ Jetson).
  - BMS -> SAFE_SHUTDOWN (cắt FET có kiểm soát) — tạm bỏ qua.
  - Dọn: thu hẹp filter CAN ({1-12,100-112,50,51-62,150}); xóa code chết ValidateJoint.
  - Đo/chỉnh: PROT_JOINT_VEL_ABS_MAX (RPM thực tế), STABLE_DELTA_DEG (rung khi đứng yên).
  - (Đã xong: bỏ clamp obs; OBS_SEVERE_ENTER=4; OBS_REINIT_CYCLES=250;
     sign-aware fall detection FALL_TILT_TAN2; falling=init+homing; TX[45]=STATUS;
     ổn định theo "ít dao động"; nrf_action gate; SPI_TIMEOUT_MS watchdog.)
================================================================================

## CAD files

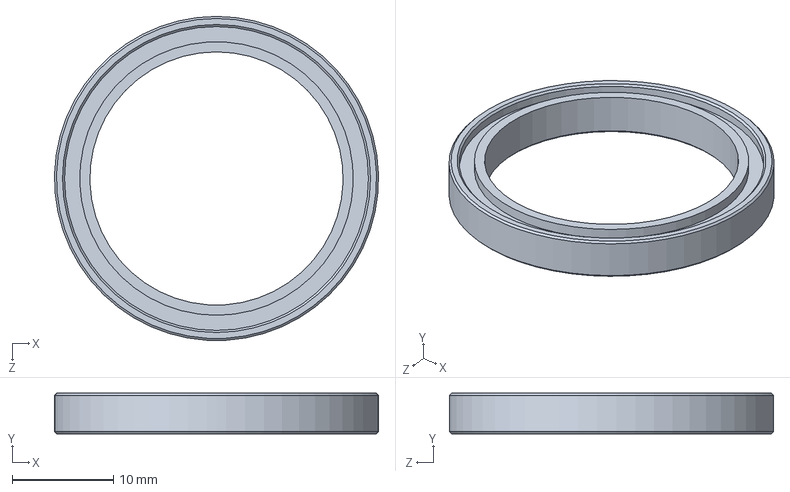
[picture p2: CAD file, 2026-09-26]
Hardware/bearing/25x32x4.SLDPRT
32.0 x 4.00 x 32.0 mm

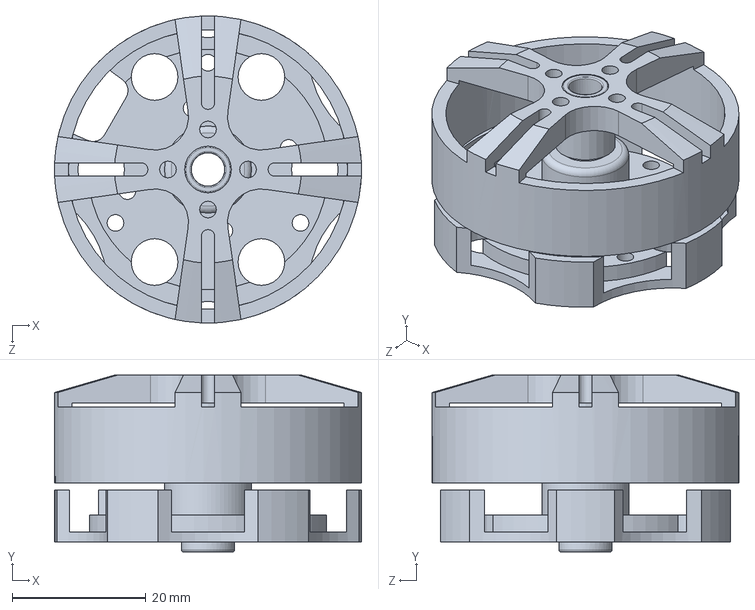
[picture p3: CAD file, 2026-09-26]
Hardware/BLDC/bldc_4108_part.SLDPRT
46.0 x 26.5 x 46.0 mm

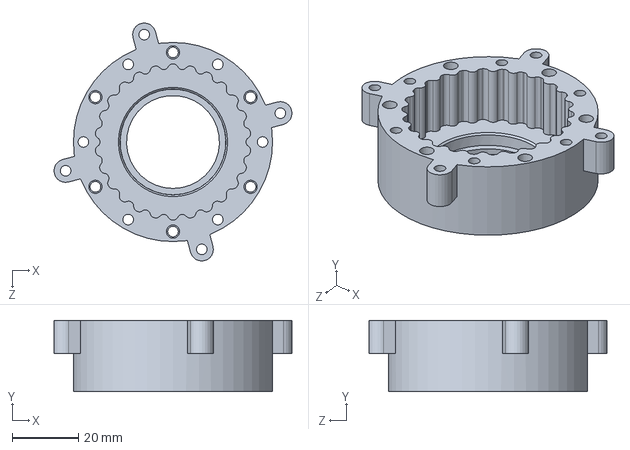
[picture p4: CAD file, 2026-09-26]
Hardware/gearbox/gearbox_3508/outer_ring_3508.SLDPRT
71.7 x 21.5 x 71.7 mm

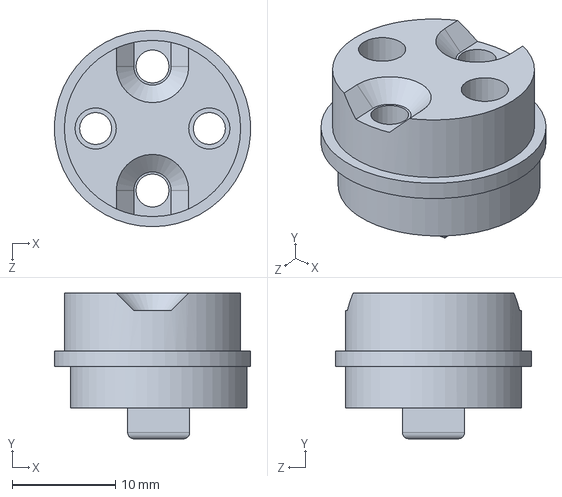
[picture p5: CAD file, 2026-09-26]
Hardware/gearbox/gearbox_3508_2/axis_3508_2_part1.SLDPRT
19.0 x 14.1 x 19.0 mm

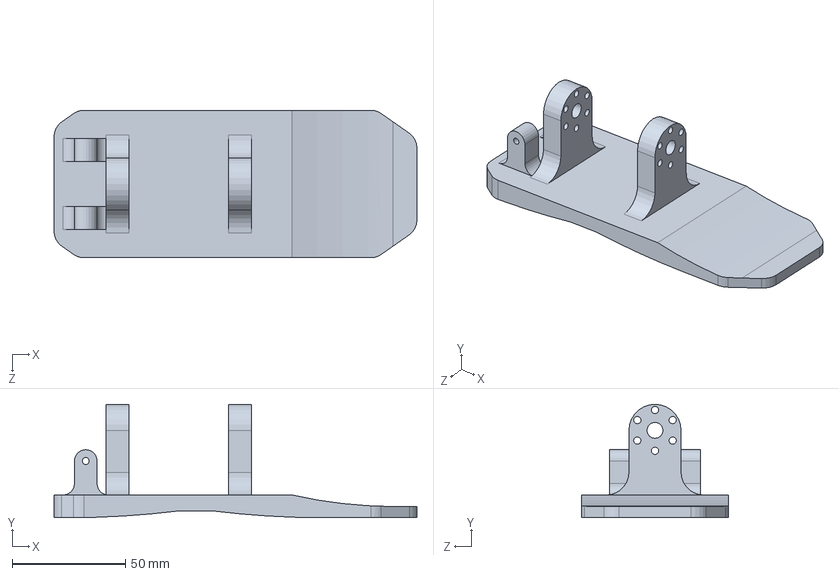
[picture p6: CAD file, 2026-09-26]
Hardware/ankle.SLDPRT
160.0 x 50.0 x 65.0 mm

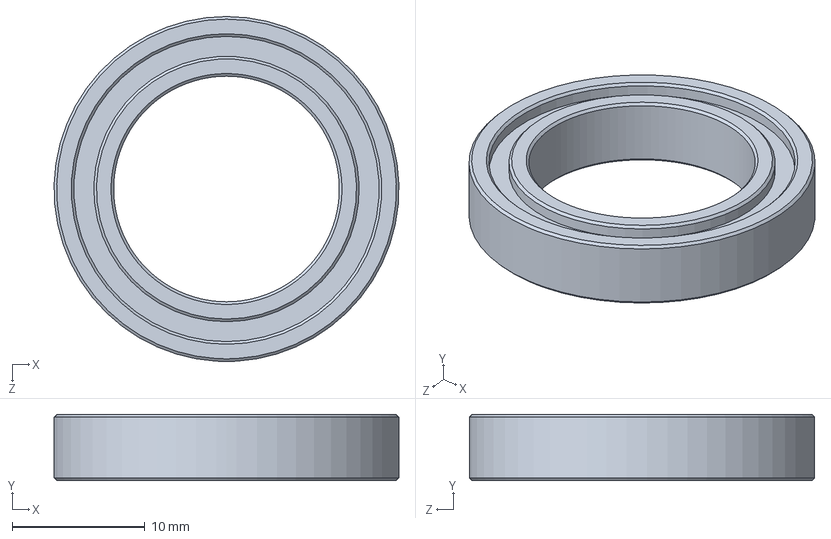
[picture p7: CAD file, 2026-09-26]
Hardware/bearing/17x26x5.SLDPRT
26.0 x 5.00 x 26.0 mm

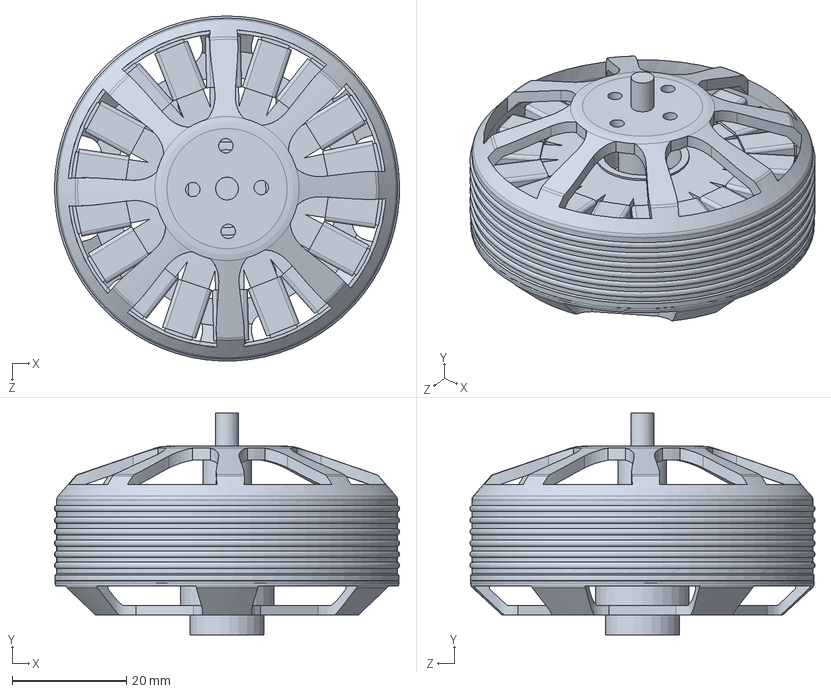
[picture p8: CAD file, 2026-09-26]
Hardware/BLDC/gartt_5210_part.SLDPRT
60.4 x 38.9 x 60.4 mm

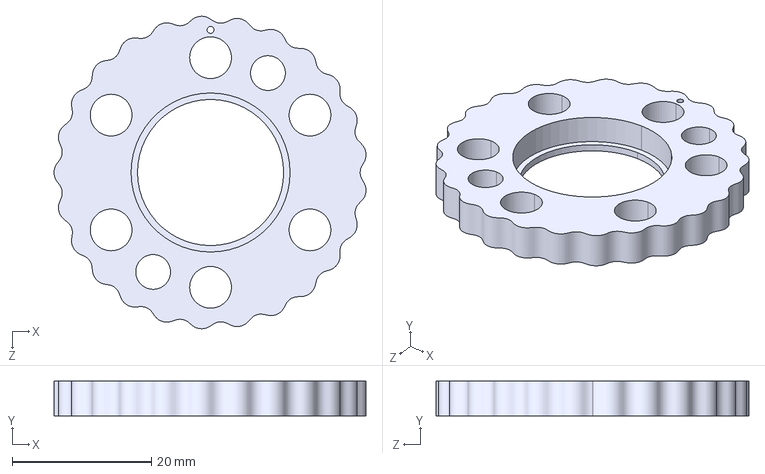
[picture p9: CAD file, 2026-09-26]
Hardware/gearbox/gearbox_3508/inner_ring_3508.STEP
44.8 x 5.00 x 44.9 mm

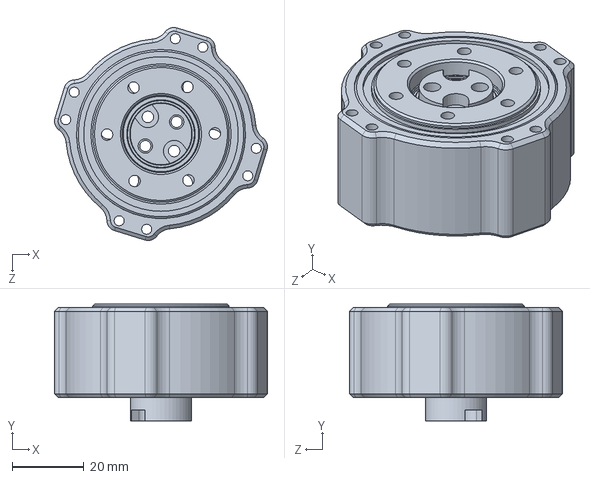
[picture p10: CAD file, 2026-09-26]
Hardware/gearbox/gearbox_3508_2/assem_3508_2_semi_part.SLDPRT
59.3 x 32.5 x 59.3 mm

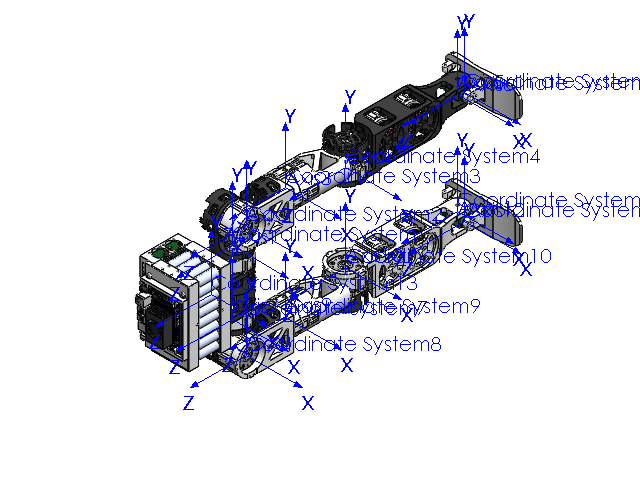
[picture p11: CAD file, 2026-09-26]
Hardware/assem_symplified.SLDASM
hip_connector
ankle x 2
ankle_connector_1 x 2
ankle_connector_2 x 4
knee_1_left
knee_1_right
knee_2_left
knee_2_right
hip_2 x 2
hip_3 x 2
bldc_5010 x 12
base_3508_2 x 4
assem_bat_7_part
base x 8
semi_assem_5210_part x 8
assem_3508_2_semi_part x 4

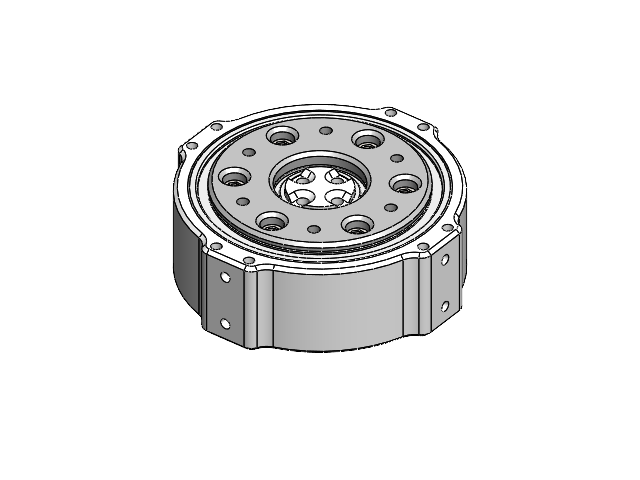
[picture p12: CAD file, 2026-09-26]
Hardware/gearbox/gearbox_5210/semi_assem_5210.SLDASM
3x8x4 x 12
shoulder_M3_12mm x 6
lid
50x65x7 x 2
17x26x5 x 2
outer_ring
20x27x4 x 2
axis

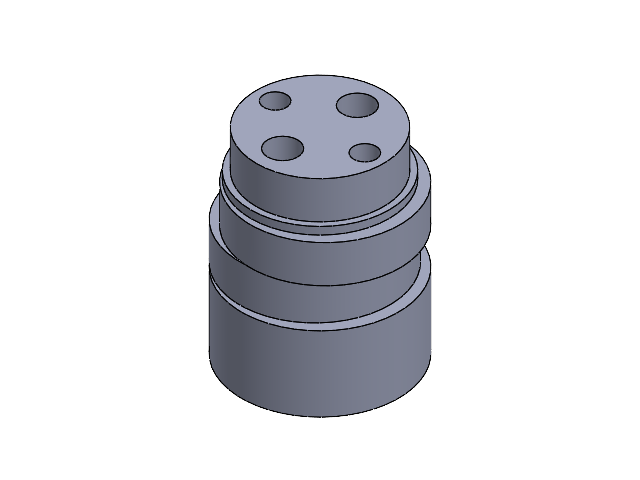
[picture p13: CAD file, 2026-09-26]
Hardware/gearbox/gearbox_5210/assem_axis.SLDASM
axis_2
axis1

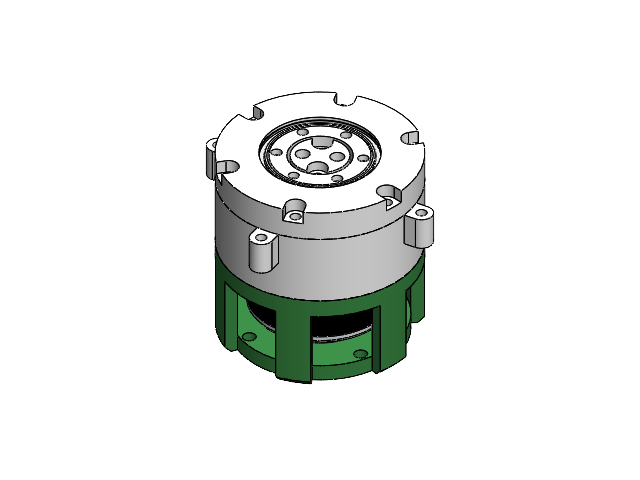
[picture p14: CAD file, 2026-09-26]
Hardware/gearbox/gearbox_3508/assem_3508.SLDASM
inner_ring_3508
outer_ring_3508
axis_3508
top_plate
25x32x4
bottom_plate
30x37x4
17x23x4 x 2
inner_ring_3508_2
bar_2mm_3508
lid_3508
gartt_3508_part
case_3508

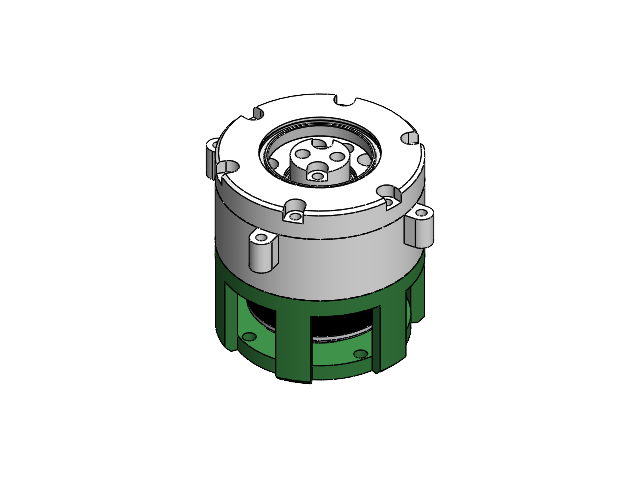
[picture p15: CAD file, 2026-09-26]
Hardware/gearbox/gearbox_3508/semi_assem_3508.SLDASM
inner_ring_3508
outer_ring_3508
axis_3508
25x32x4
bottom_plate
30x37x4
17x23x4 x 2
inner_ring_3508_2
bar_2mm_3508
lid_3508
gartt_3508_part
case_3508

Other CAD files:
Hardware/gearbox/gearbox_5210/assem_5010.SLDASM
Hardware/gearbox/gearbox_3508_2/assem_3508_2_semi.SLDASM
Hardware/gearbox/gearbox_5210/Assem1.SLDASM
Hardware/gearbox/gearbox_3508_2/assem_3508_2.SLDASM
Hardware/BLDC/gartt_3508_part.SLDPRT
Hardware/Jetson Nano.step
Hardware/ankle_connector_1.SLDPRT
Hardware/ankle_connector_2.SLDPRT
Hardware/ball.SLDPRT
Hardware/bar_3mm_139mm.SLDPRT
Hardware/bar_3mm_72mm.SLDPRT
Hardware/bearing/12x18x4.SLDPRT
Hardware/bearing/17x23x4.SLDPRT
Hardware/bearing/20x27x4.SLDPRT
Hardware/bearing/2x5x2.5.SLDPRT
Hardware/bearing/30x37x4.SLDPRT
Hardware/bearing/35x47x7.SLDPRT
Hardware/bearing/3x8x4.SLDPRT
Hardware/bearing/50x65x7.SLDPRT
Hardware/bearing/5x13x4.SLDPRT
Hardware/bearing/8x16x5.SLDPRT
Hardware/bearing_joint_1.SLDPRT
Hardware/gearbox/gearbox_3508/axis_3508.SLDPRT
Hardware/gearbox/gearbox_3508/bar_2mm_3508.SLDPRT
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

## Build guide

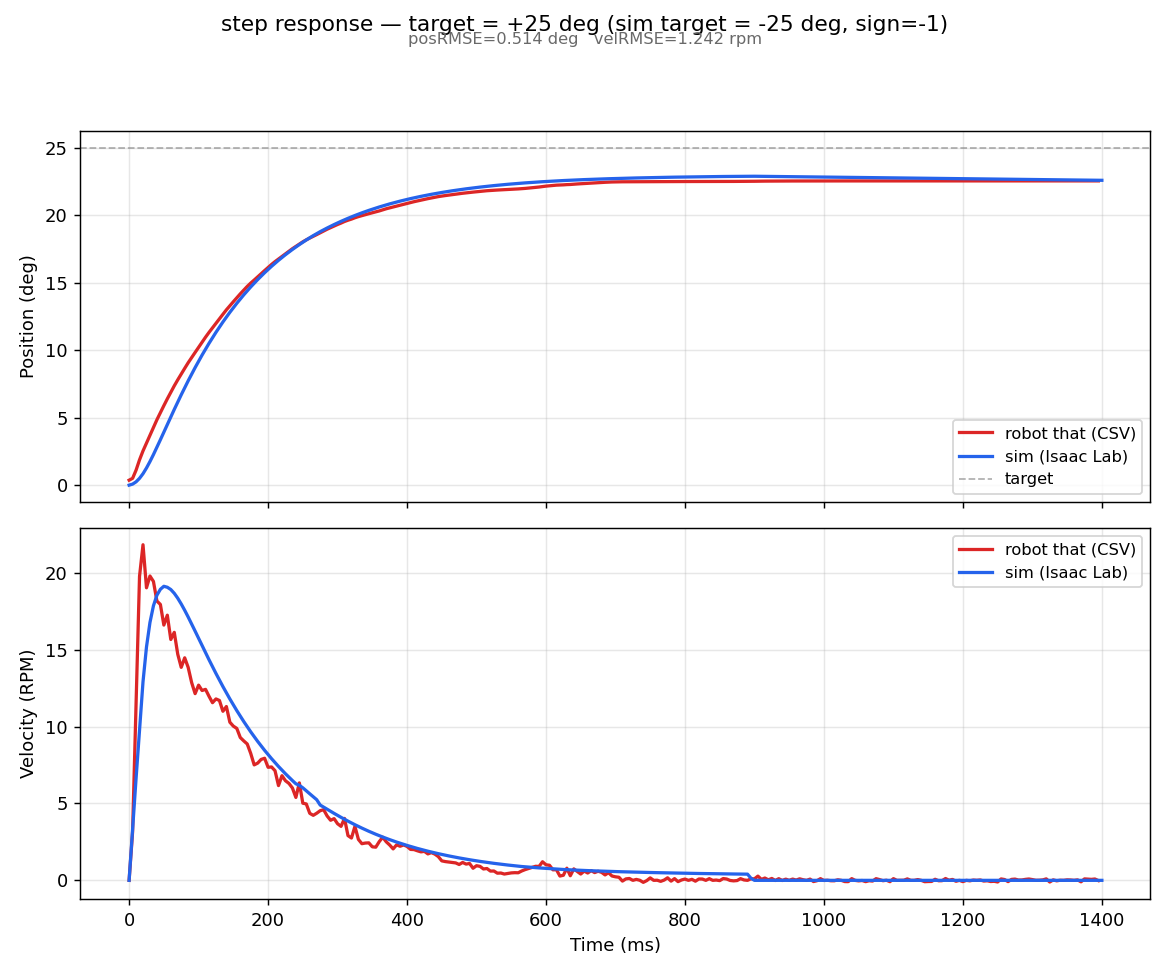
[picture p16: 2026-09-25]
step_response_data/right_hip_pitch_joint/compare_target_25.png

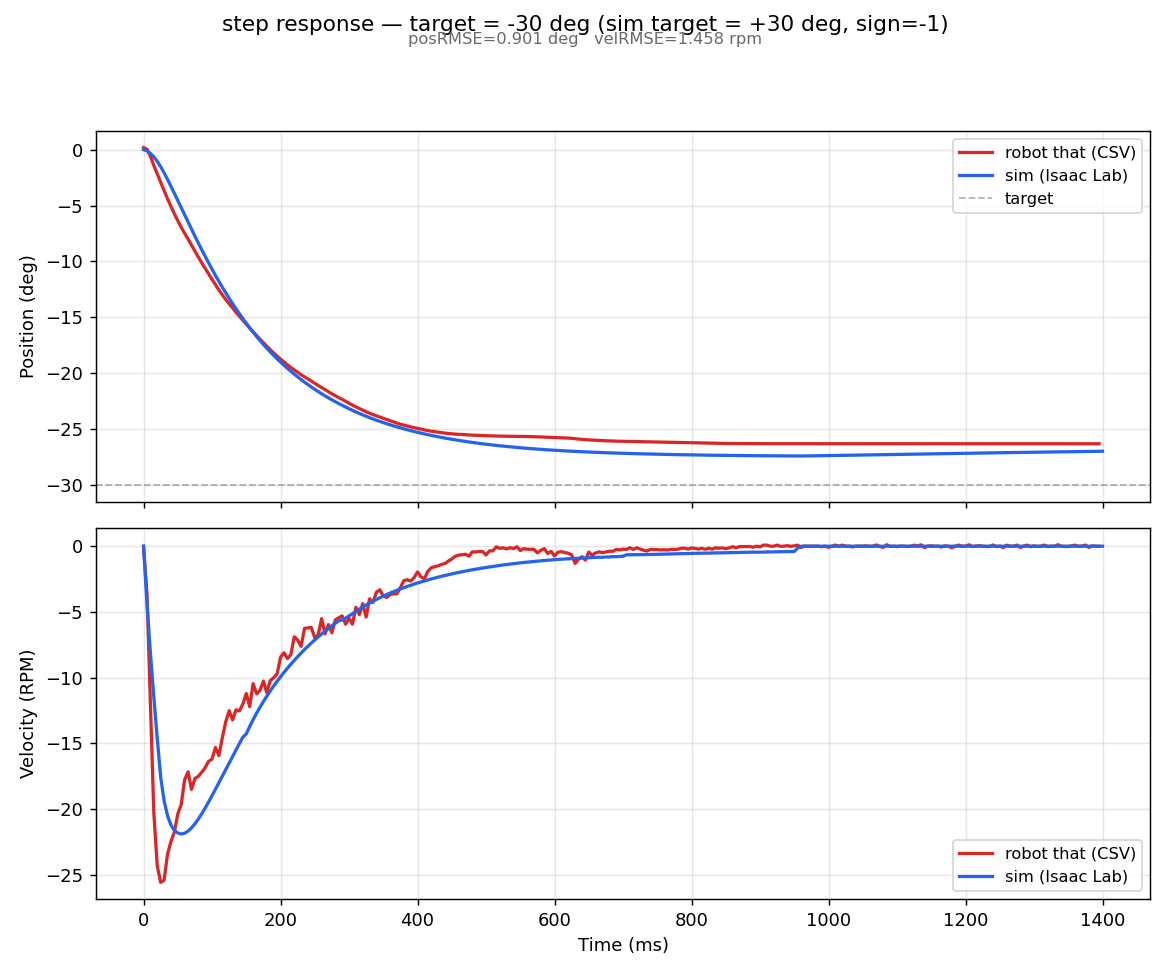
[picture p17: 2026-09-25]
step_response_data/right_hip_pitch_joint/compare_target_-30.png

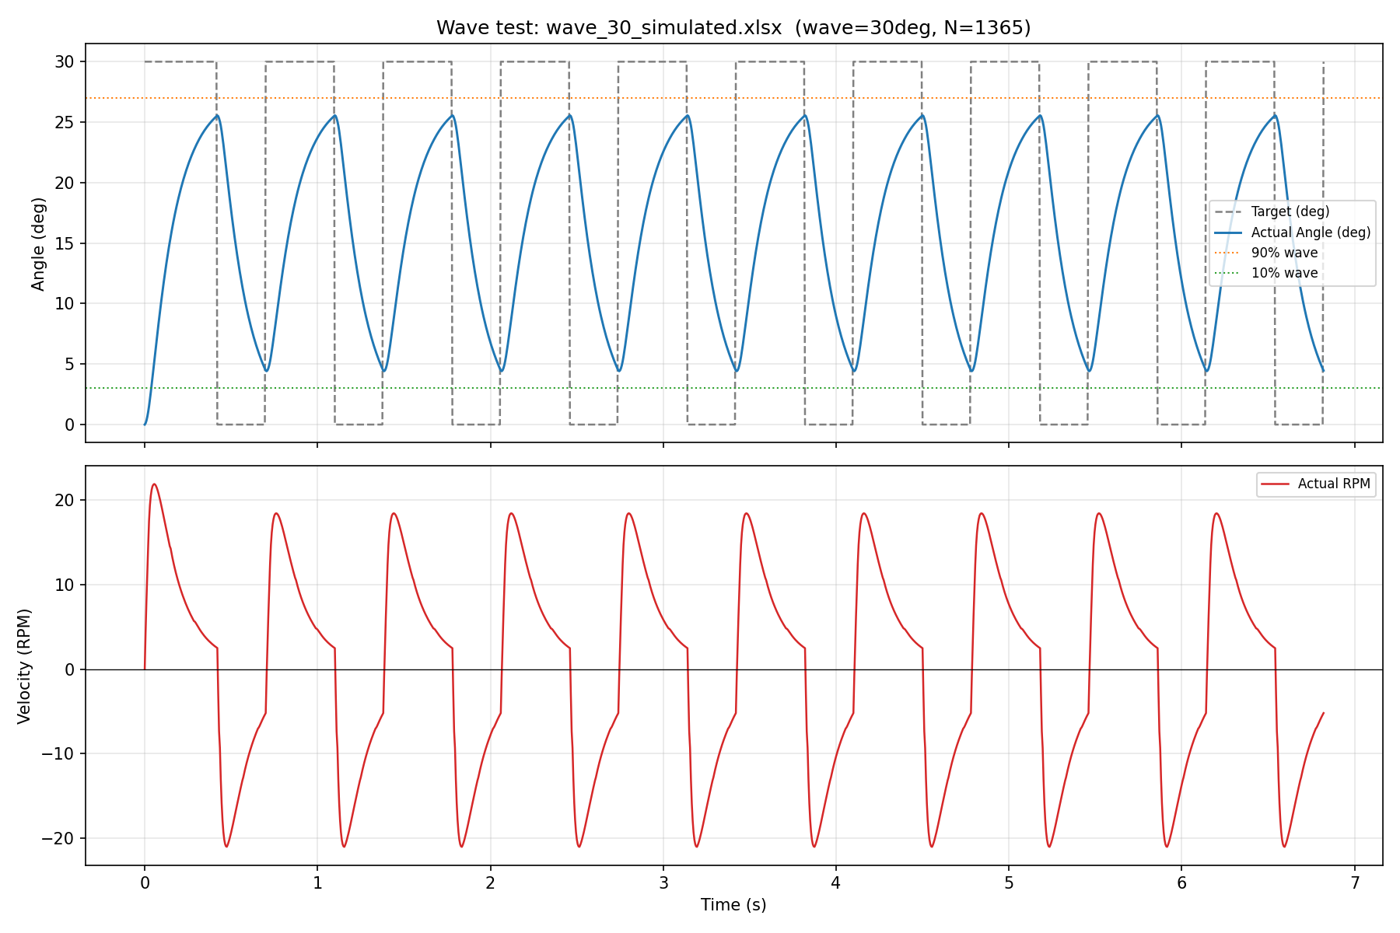
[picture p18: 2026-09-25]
step_response_data/right_hip_pitch_joint_wave/wave_30_simulated_plot.png

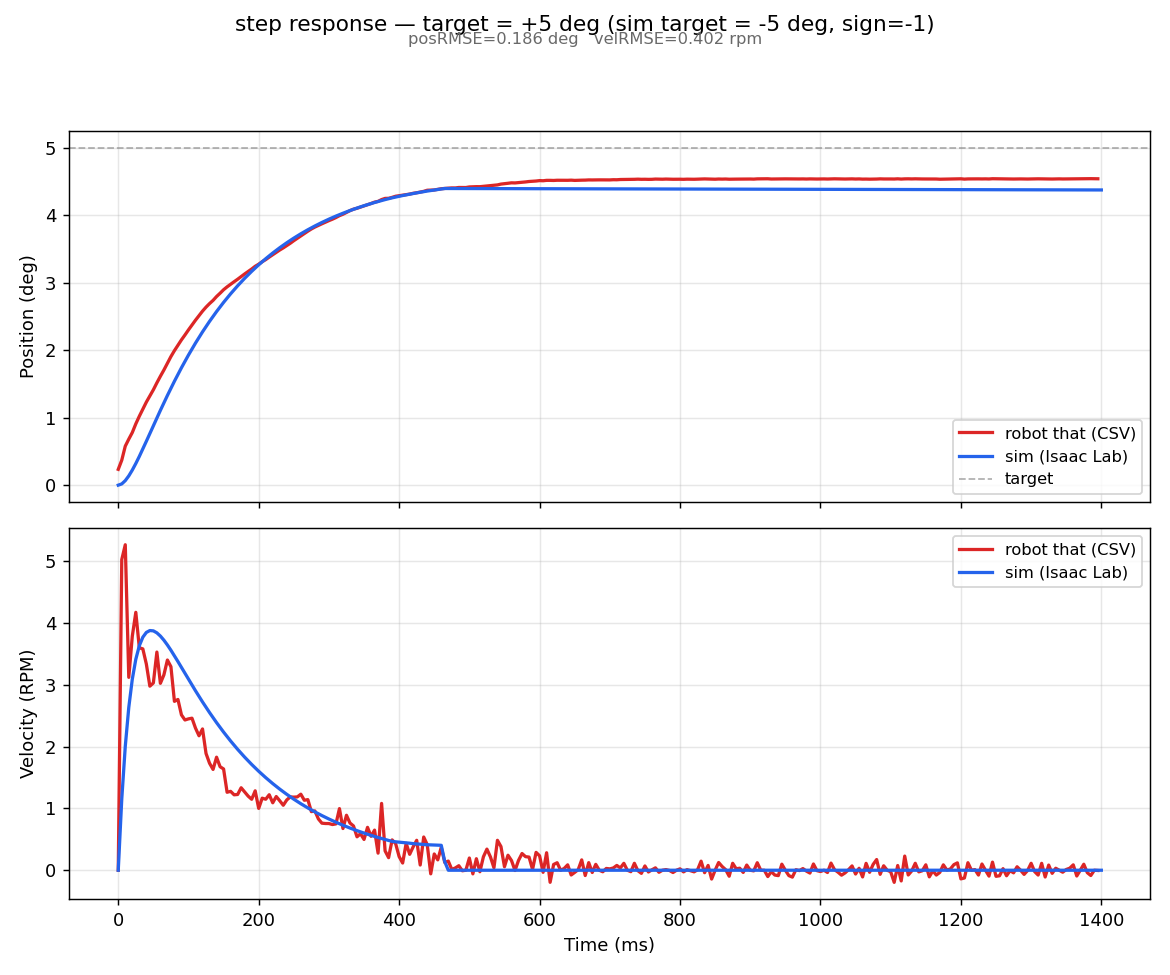
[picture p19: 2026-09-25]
step_response_data/right_hip_pitch_joint/compare_target_5.png

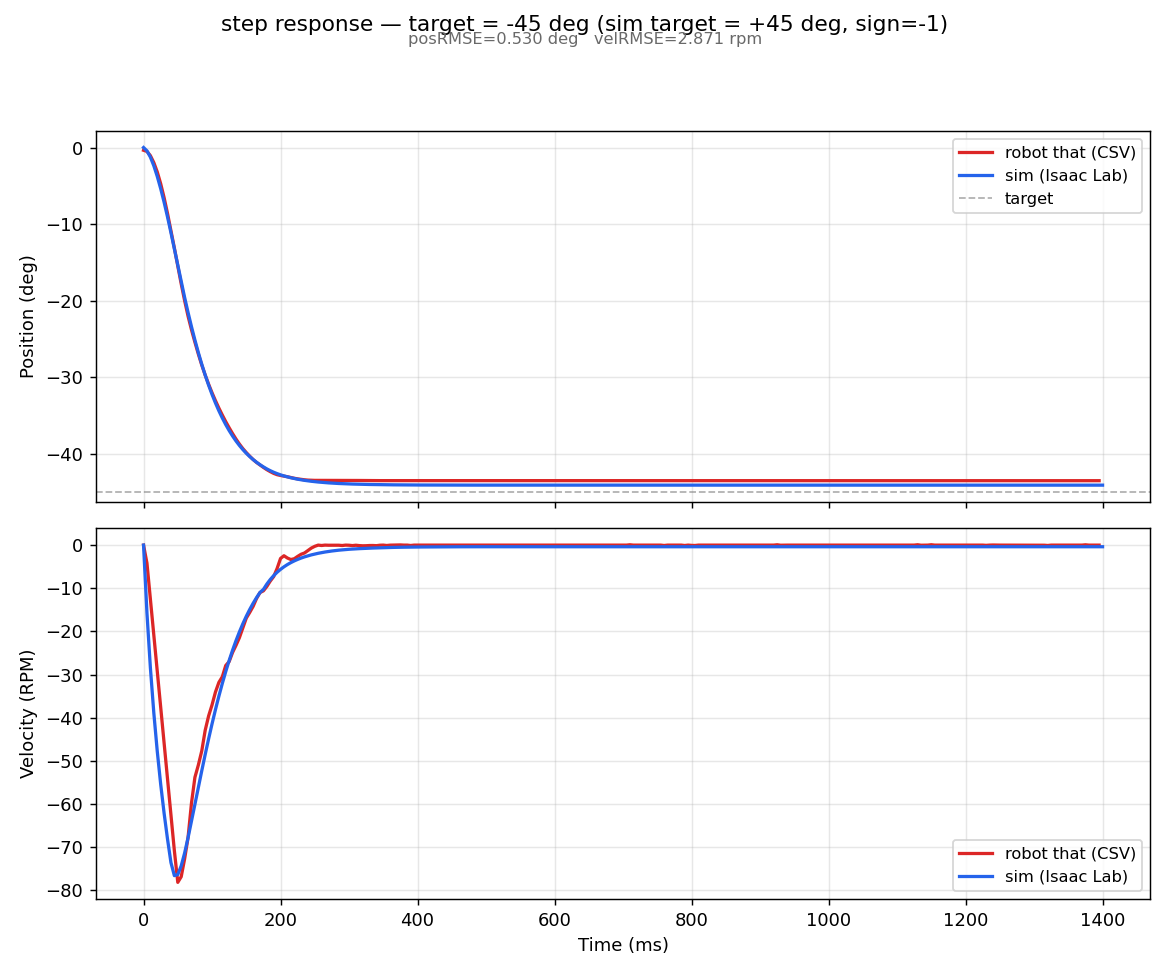
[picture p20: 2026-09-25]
step_response_data/right_knee_joint/compare_target_-45.png

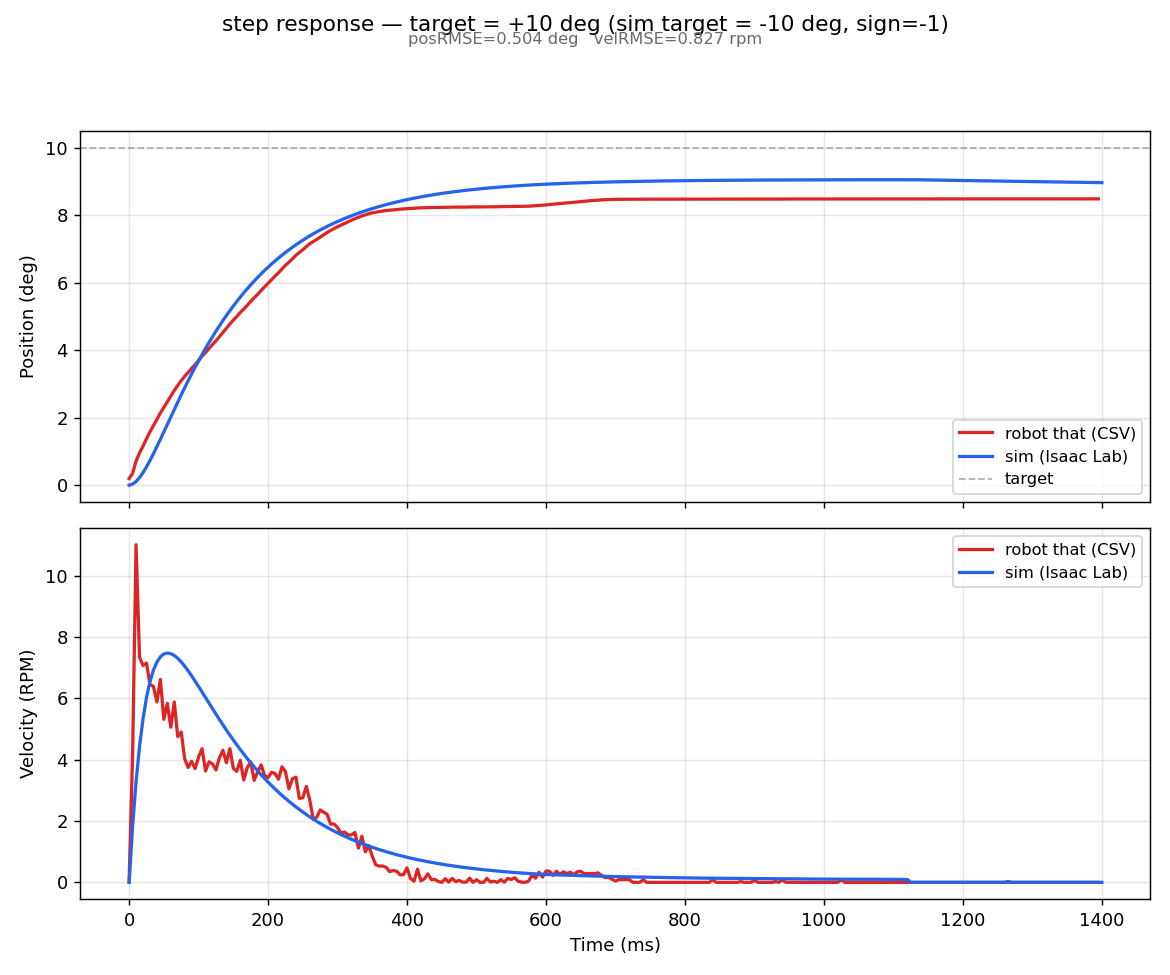
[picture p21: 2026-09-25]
step_response_data/right_hip_roll_joint/compare_target_10.png

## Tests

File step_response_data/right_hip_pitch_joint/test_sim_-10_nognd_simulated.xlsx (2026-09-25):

Index (số sample): | 281
Target Position: | -10
Sample | Time Step | Actual Angle | Actual RPM | Torque (Nm) | Obstacle | Ground
0 | 0 | 0.0006 | 0 | -0.0005 | OFF | OFF
1 | 5 | -0.0371 | -2.2799 | -7.8545 | OFF | OFF
2 | 10 | -0.1332 | -3.9819 | -6.0342 | OFF | OFF
3 | 15 | -0.2725 | -5.2379 | -4.622 | OFF | OFF
4 | 20 | -0.4433 | -6.148 | -3.5262 | OFF | OFF
5 | 25 | -0.6366 | -6.7907 | -2.6772 | OFF | OFF
6 | 30 | -0.8456 | -7.2266 | -2.0206 | OFF | OFF
7 | 35 | -1.0648 | -7.5034 | -1.5141 | OFF | OFF
8 | 40 | -1.2901 | -7.658 | -1.1245 | OFF | OFF
9 | 45 | -1.5184 | -7.7193 | -0.8261 | OFF | OFF
10 | 50 | -1.7473 | -7.7095 | -0.5987 | OFF | OFF
11 | 55 | -1.975 | -7.6463 | -0.4266 | OFF | OFF
12 | 60 | -2.2 | -7.5431 | -0.2975 | OFF | OFF
13 | 65 | -2.4214 | -7.4104 | -0.2018 | OFF | OFF
14 | 70 | -2.6384 | -7.2565 | -0.1321 | OFF | OFF
15 | 75 | -2.8505 | -7.0876 | -0.0825 | OFF | OFF
16 | 80 | -3.0574 | -6.9087 | -0.0486 | OFF | OFF
17 | 85 | -3.2588 | -6.7235 | -0.0266 | OFF | OFF
18 | 90 | -3.4546 | -6.5349 | -0.0139 | OFF | OFF
19 | 95 | -3.6447 | -6.3451 | -0.0082 | OFF | OFF
20 | 100 | -3.8291 | -6.1558 | -0.008 | OFF | OFF
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

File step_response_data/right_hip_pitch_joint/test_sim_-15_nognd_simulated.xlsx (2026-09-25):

Index (số sample): | 281
Target Position: | -15
Sample | Time Step | Actual Angle | Actual RPM | Torque (Nm) | Obstacle | Ground
0 | 0 | 0.0006 | 0 | -0.0005 | OFF | OFF
1 | 5 | -0.0556 | -3.3479 | -10 | OFF | OFF
2 | 10 | -0.1977 | -5.9126 | -9.1079 | OFF | OFF
3 | 15 | -0.4049 | -7.8057 | -6.982 | OFF | OFF
4 | 20 | -0.6596 | -9.1783 | -5.3324 | OFF | OFF
5 | 25 | -0.9483 | -10.1481 | -4.0543 | OFF | OFF
6 | 30 | -1.2606 | -10.8068 | -3.0658 | OFF | OFF
7 | 35 | -1.5884 | -11.2259 | -2.3032 | OFF | OFF
8 | 40 | -1.9255 | -11.461 | -1.7166 | OFF | OFF
9 | 45 | -2.2671 | -11.5554 | -1.2673 | OFF | OFF
10 | 50 | -2.6097 | -11.543 | -0.9248 | OFF | OFF
11 | 55 | -2.9504 | -11.4499 | -0.6655 | OFF | OFF
12 | 60 | -3.2873 | -11.2966 | -0.471 | OFF | OFF
13 | 65 | -3.6188 | -11.0989 | -0.3268 | OFF | OFF
14 | 70 | -3.9437 | -10.8692 | -0.2217 | OFF | OFF
15 | 75 | -4.2614 | -10.6169 | -0.1469 | OFF | OFF
16 | 80 | -4.5712 | -10.3495 | -0.0956 | OFF | OFF
17 | 85 | -4.8728 | -10.0725 | -0.0623 | OFF | OFF
18 | 90 | -5.166 | -9.7903 | -0.043 | OFF | OFF
19 | 95 | -5.4507 | -9.5063 | -0.0343 | OFF | OFF
20 | 100 | -5.7268 | -9.2229 | -0.0338 | OFF | OFF
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

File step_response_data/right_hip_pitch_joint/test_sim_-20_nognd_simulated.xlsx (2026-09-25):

Index (số sample): | 281
Target Position: | -20
Sample | Time Step | Actual Angle | Actual RPM | Torque (Nm) | Obstacle | Ground
0 | 0 | 0.0006 | 0 | -0.0005 | OFF | OFF
1 | 5 | -0.0684 | -3.3477 | -10 | OFF | OFF
2 | 10 | -0.228 | -6.6163 | -10 | OFF | OFF
3 | 15 | -0.4718 | -9.4597 | -10 | OFF | OFF
4 | 20 | -0.7873 | -11.5376 | -7.9078 | OFF | OFF
5 | 25 | -1.1546 | -13.0228 | -6.028 | OFF | OFF
6 | 30 | -1.5584 | -14.0498 | -4.573 | OFF | OFF
7 | 35 | -1.9866 | -14.7234 | -3.4494 | OFF | OFF
8 | 40 | -2.4303 | -15.1251 | -2.584 | OFF | OFF
9 | 45 | -2.8823 | -15.3187 | -1.92 | OFF | OFF
10 | 50 | -3.3371 | -15.3558 | -1.4129 | OFF | OFF
11 | 55 | -3.7906 | -15.2741 | -1.0266 | OFF | OFF
12 | 60 | -4.2401 | -15.1018 | -0.7346 | OFF | OFF
13 | 65 | -4.6831 | -14.8639 | -0.5168 | OFF | OFF
14 | 70 | -5.118 | -14.5766 | -0.3558 | OFF | OFF
15 | 75 | -5.5436 | -14.2542 | -0.2399 | OFF | OFF
16 | 80 | -5.9592 | -13.9075 | -0.1588 | OFF | OFF
17 | 85 | -6.364 | -13.5449 | -0.1047 | OFF | OFF
18 | 90 | -6.7578 | -13.1731 | -0.0715 | OFF | OFF
19 | 95 | -7.1404 | -12.7969 | -0.0542 | OFF | OFF
20 | 100 | -7.5118 | -12.4188 | -0.0492 | OFF | OFF
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

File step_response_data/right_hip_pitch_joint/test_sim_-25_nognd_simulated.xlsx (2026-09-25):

Index (số sample): | 281
Target Position: | -25
Sample | Time Step | Actual Angle | Actual RPM | Torque (Nm) | Obstacle | Ground
0 | 0 | 0.0006 | 0 | -0.0005 | OFF | OFF
1 | 5 | -0.0757 | -3.3476 | -10 | OFF | OFF
2 | 10 | -0.2455 | -6.6159 | -10 | OFF | OFF
3 | 15 | -0.5047 | -9.805 | -10 | OFF | OFF
4 | 20 | -0.8476 | -12.9147 | -10 | OFF | OFF
5 | 25 | -1.2687 | -15.1756 | -8.826 | OFF | OFF
6 | 30 | -1.7457 | -16.7725 | -6.7196 | OFF | OFF
7 | 35 | -2.2616 | -17.8566 | -5.0907 | OFF | OFF
8 | 40 | -2.803 | -18.5457 | -3.8341 | OFF | OFF
9 | 45 | -3.3598 | -18.9313 | -2.8677 | OFF | OFF
10 | 50 | -3.9239 | -19.1275 | -2.1276 | OFF | OFF
11 | 55 | -4.4892 | -19.0645 | -1.5305 | OFF | OFF
12 | 60 | -5.051 | -18.9171 | -1.1359 | OFF | OFF
13 | 65 | -5.6063 | -18.6708 | -0.8104 | OFF | OFF
14 | 70 | -6.1527 | -18.3514 | -0.5678 | OFF | OFF
15 | 75 | -6.6885 | -17.9778 | -0.3895 | OFF | OFF
16 | 80 | -7.2123 | -17.5672 | -0.2621 | OFF | OFF
17 | 85 | -7.7232 | -17.1302 | -0.1732 | OFF | OFF
18 | 90 | -8.2207 | -16.6763 | -0.1151 | OFF | OFF
19 | 95 | -8.7046 | -16.2114 | -0.0809 | OFF | OFF
20 | 100 | -9.1746 | -15.7431 | -0.0659 | OFF | OFF
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

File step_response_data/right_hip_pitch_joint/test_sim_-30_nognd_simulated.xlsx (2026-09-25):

Index (số sample): | 281
Target Position: | -30
Sample | Time Step | Actual Angle | Actual RPM | Torque (Nm) | Obstacle | Ground
0 | 0 | 0.0006 | 0 | -0.0005 | OFF | OFF
1 | 5 | -0.0803 | -3.3475 | -10 | OFF | OFF
2 | 10 | -0.2564 | -6.6157 | -10 | OFF | OFF
3 | 15 | -0.5241 | -9.8044 | -10 | OFF | OFF
4 | 20 | -0.8798 | -12.9135 | -10 | OFF | OFF
5 | 25 | -1.3185 | -15.943 | -10 | OFF | OFF
6 | 30 | -1.8337 | -18.4697 | -10 | OFF | OFF
7 | 35 | -2.4114 | -20.2433 | -7.6157 | OFF | OFF
8 | 40 | -3.032 | -21.4356 | -5.769 | OFF | OFF
9 | 45 | -3.6804 | -22.1803 | -4.3451 | OFF | OFF
10 | 50 | -4.3451 | -22.5816 | -3.251 | OFF | OFF
11 | 55 | -5.0169 | -22.8493 | -2.4137 | OFF | OFF
12 | 60 | -5.6898 | -22.6588 | -1.6759 | OFF | OFF
13 | 65 | -6.3568 | -22.4615 | -1.297 | OFF | OFF
14 | 70 | -7.0153 | -22.1536 | -0.9282 | OFF | OFF
15 | 75 | -7.6628 | -21.7632 | -0.6527 | OFF | OFF
16 | 80 | -8.2973 | -21.3131 | -0.4508 | OFF | OFF
17 | 85 | -8.9175 | -20.8195 | -0.306 | OFF | OFF
18 | 90 | -9.5223 | -20.2965 | -0.2066 | OFF | OFF
19 | 95 | -10.1111 | -19.7549 | -0.1423 | OFF | OFF
20 | 100 | -10.6835 | -19.2031 | -0.1052 | OFF | OFF
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

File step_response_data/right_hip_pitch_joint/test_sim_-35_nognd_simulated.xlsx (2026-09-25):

Index (số sample): | 281
Target Position: | -35
Sample | Time Step | Actual Angle | Actual RPM | Torque (Nm) | Obstacle | Ground
0 | 0 | 0.0006 | 0 | -0.0005 | OFF | OFF
1 | 5 | -0.0836 | -3.3475 | -10 | OFF | OFF
2 | 10 | -0.2639 | -6.6155 | -10 | OFF | OFF
3 | 15 | -0.5371 | -9.804 | -10 | OFF | OFF
4 | 20 | -0.9002 | -12.9128 | -10 | OFF | OFF
5 | 25 | -1.3494 | -15.9417 | -10 | OFF | OFF
6 | 30 | -1.8805 | -18.8907 | -10 | OFF | OFF
7 | 35 | -2.4875 | -21.6809 | -10 | OFF | OFF
8 | 40 | -3.1633 | -23.6301 | -8.5072 | OFF | OFF
9 | 45 | -3.886 | -24.9304 | -6.4455 | OFF | OFF
10 | 50 | -4.6389 | -25.7312 | -4.8566 | OFF | OFF
11 | 55 | -5.4091 | -26.1489 | -3.6363 | OFF | OFF
12 | 60 | -6.1862 | -26.4117 | -2.7034 | OFF | OFF
13 | 65 | -6.964 | -26.1756 | -1.8866 | OFF | OFF
14 | 70 | -7.7336 | -25.9313 | -1.4611 | OFF | OFF
15 | 75 | -8.4932 | -25.5621 | -1.0486 | OFF | OFF
16 | 80 | -9.2397 | -25.1012 | -0.742 | OFF | OFF
17 | 85 | -9.971 | -24.5742 | -0.5176 | OFF | OFF
18 | 90 | -10.6854 | -24.0008 | -0.3572 | OFF | OFF
19 | 95 | -11.3819 | -23.3947 | -0.2465 | OFF | OFF
20 | 100 | -12.0599 | -22.7681 | -0.1754 | OFF | OFF
21 | 105 | -12.719 | -22.1304 | -0.135 | OFF | OFF
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

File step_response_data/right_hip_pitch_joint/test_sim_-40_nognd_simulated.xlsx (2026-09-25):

Index (số sample): | 281
Target Position: | -40
Sample | Time Step | Actual Angle | Actual RPM | Torque (Nm) | Obstacle | Ground
0 | 0 | 0.0006 | 0 | -0.0005 | OFF | OFF
1 | 5 | -0.0861 | -3.3475 | -10 | OFF | OFF
2 | 10 | -0.2693 | -6.6154 | -10 | OFF | OFF
3 | 15 | -0.5462 | -9.8037 | -10 | OFF | OFF
4 | 20 | -0.9139 | -12.9122 | -10 | OFF | OFF
5 | 25 | -1.3694 | -15.9408 | -10 | OFF | OFF
6 | 30 | -1.9094 | -18.8893 | -10 | OFF | OFF
7 | 35 | -2.5297 | -21.7576 | -10 | OFF | OFF
8 | 40 | -3.2254 | -24.5458 | -10 | OFF | OFF
9 | 45 | -3.9901 | -26.736 | -9.6045 | OFF | OFF
10 | 50 | -4.8075 | -28.1956 | -7.2837 | OFF | OFF
11 | 55 | -5.6587 | -29.0931 | -5.4954 | OFF | OFF
12 | 60 | -6.5293 | -29.5593 | -4.122 | OFF | OFF
13 | 65 | -7.4073 | -29.8568 | -3.072 | OFF | OFF
14 | 70 | -8.2864 | -29.5811 | -2.1487 | OFF | OFF
15 | 75 | -9.1559 | -29.3029 | -1.6748 | OFF | OFF
16 | 80 | -10.0139 | -28.8857 | -1.2105 | OFF | OFF
17 | 85 | -10.8571 | -28.365 | -0.8643 | OFF | OFF
18 | 90 | -11.6829 | -27.7712 | -0.611 | OFF | OFF
19 | 95 | -12.4898 | -27.1233 | -0.4287 | OFF | OFF
20 | 100 | -13.2764 | -26.4402 | -0.3039 | OFF | OFF
21 | 105 | -14.0421 | -25.7336 | -0.2226 | OFF | OFF
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

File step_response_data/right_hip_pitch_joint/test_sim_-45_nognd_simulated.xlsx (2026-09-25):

Index (số sample): | 281
Target Position: | -45
Sample | Time Step | Actual Angle | Actual RPM | Torque (Nm) | Obstacle | Ground
0 | 0 | 0.0006 | 0 | -0.0005 | OFF | OFF
1 | 5 | -0.088 | -3.3474 | -10 | OFF | OFF
2 | 10 | -0.2734 | -6.6153 | -10 | OFF | OFF
3 | 15 | -0.553 | -9.8035 | -10 | OFF | OFF
4 | 20 | -0.9241 | -12.9118 | -10 | OFF | OFF
5 | 25 | -1.3839 | -15.9401 | -10 | OFF | OFF
6 | 30 | -1.9294 | -18.8882 | -10 | OFF | OFF
7 | 35 | -2.5573 | -21.756 | -10 | OFF | OFF
8 | 40 | -3.264 | -24.5435 | -10 | OFF | OFF
9 | 45 | -4.045 | -27.2505 | -10 | OFF | OFF
10 | 50 | -4.8941 | -29.7016 | -10 | OFF | OFF
11 | 55 | -5.8022 | -31.3365 | -8.1716 | OFF | OFF
12 | 60 | -6.7483 | -32.3434 | -6.1743 | OFF | OFF
13 | 65 | -7.716 | -32.8686 | -4.6404 | OFF | OFF
14 | 70 | -8.6925 | -33.2047 | -3.4678 | OFF | OFF
15 | 75 | -9.6699 | -32.9031 | -2.437 | OFF | OFF
16 | 80 | -10.6366 | -32.5982 | -1.9062 | OFF | OFF
17 | 85 | -11.591 | -32.1361 | -1.3864 | OFF | OFF
18 | 90 | -12.5288 | -31.5601 | -0.9998 | OFF | OFF
19 | 95 | -13.4474 | -30.9004 | -0.7156 | OFF | OFF
20 | 100 | -14.3449 | -30.1821 | -0.5122 | OFF | OFF
21 | 105 | -15.2199 | -29.4241 | -0.3715 | OFF | OFF
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

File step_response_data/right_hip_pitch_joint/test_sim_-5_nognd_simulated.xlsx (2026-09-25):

Index (số sample): | 281
Target Position: | -5
Sample | Time Step | Actual Angle | Actual RPM | Torque (Nm) | Obstacle | Ground
0 | 0 | 0.0006 | 0 | -0.0005 | OFF | OFF
1 | 5 | -0.0178 | -1.1522 | -3.9275 | OFF | OFF
2 | 10 | -0.0664 | -2.0066 | -3.0081 | OFF | OFF
3 | 15 | -0.1366 | -2.637 | -2.2989 | OFF | OFF
4 | 20 | -0.2227 | -3.0938 | -1.7486 | OFF | OFF
5 | 25 | -0.3201 | -3.4162 | -1.3223 | OFF | OFF
6 | 30 | -0.4253 | -3.6348 | -0.9926 | OFF | OFF
7 | 35 | -0.5356 | -3.7735 | -0.7382 | OFF | OFF
8 | 40 | -0.6491 | -3.8509 | -0.5426 | OFF | OFF
9 | 45 | -0.764 | -3.8813 | -0.3927 | OFF | OFF
10 | 50 | -0.8792 | -3.8762 | -0.2786 | OFF | OFF
11 | 55 | -0.9937 | -3.8441 | -0.1922 | OFF | OFF
12 | 60 | -1.107 | -3.792 | -0.1273 | OFF | OFF
13 | 65 | -1.2184 | -3.7252 | -0.0793 | OFF | OFF
14 | 70 | -1.3276 | -3.6476 | -0.0444 | OFF | OFF
15 | 75 | -1.4343 | -3.5626 | -0.0195 | OFF | OFF
16 | 80 | -1.5384 | -3.4725 | -0.0024 | OFF | OFF
17 | 85 | -1.6397 | -3.3793 | 0.0086 | OFF | OFF
18 | 90 | -1.7382 | -3.2844 | 0.0149 | OFF | OFF
19 | 95 | -1.8339 | -3.1888 | 0.0177 | OFF | OFF
20 | 100 | -1.9266 | -3.0935 | 0.0178 | OFF | OFF
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

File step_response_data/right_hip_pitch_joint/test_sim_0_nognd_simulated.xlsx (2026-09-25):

Index (số sample): | 281
Target Position: | 0
Sample | Time Step | Actual Angle | Actual RPM | Torque (Nm) | Obstacle | Ground
0 | 0 | 0.0006 | 0 | -0.0005 | OFF | OFF
1 | 5 | 0.0007 | 0 | -0.0005 | OFF | OFF
2 | 10 | 0.0007 | 0 | -0.0005 | OFF | OFF
3 | 15 | 0.0007 | 0 | -0.0005 | OFF | OFF
4 | 20 | 0.0007 | 0 | -0.0006 | OFF | OFF
5 | 25 | 0.0008 | 0 | -0.0006 | OFF | OFF
6 | 30 | 0.0008 | 0 | -0.0006 | OFF | OFF
7 | 35 | 0.0008 | 0 | -0.0006 | OFF | OFF
8 | 40 | 0.0009 | 0 | -0.0007 | OFF | OFF
9 | 45 | 0.0009 | 0 | -0.0007 | OFF | OFF
10 | 50 | 0.0009 | 0 | -0.0007 | OFF | OFF
11 | 55 | 0.001 | 0 | -0.0007 | OFF | OFF
12 | 60 | 0.001 | 0 | -0.0008 | OFF | OFF
13 | 65 | 0.001 | 0 | -0.0008 | OFF | OFF
14 | 70 | 0.0011 | 0 | -0.0008 | OFF | OFF
15 | 75 | 0.0011 | 0 | -0.0008 | OFF | OFF
16 | 80 | 0.0011 | 0 | -0.0009 | OFF | OFF
17 | 85 | 0.0012 | 0 | -0.0009 | OFF | OFF
18 | 90 | 0.0012 | 0 | -0.0009 | OFF | OFF
19 | 95 | 0.0012 | 0 | -0.0009 | OFF | OFF
20 | 100 | 0.0012 | 0 | -0.0009 | OFF | OFF
21 | 105 | 0.0013 | 0 | -0.001 | OFF | OFF
22 | 110 | 0.0013 | 0 | -0.001 | OFF | OFF
23 | 115 | 0.0013 | 0 | -0.001 | OFF | OFF
24 | 120 | 0.0014 | 0 | -0.001 | OFF | OFF
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

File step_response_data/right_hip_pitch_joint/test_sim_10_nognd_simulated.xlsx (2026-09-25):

Index (số sample): | 281
Target Position: | 10
Sample | Time Step | Actual Angle | Actual RPM | Torque (Nm) | Obstacle | Ground
0 | 0 | 0.0006 | 0 | -0.0005 | OFF | OFF
1 | 5 | 0.0496 | 2.9011 | 7.8535 | OFF | OFF
2 | 10 | 0.1625 | 4.595 | 5.5365 | OFF | OFF
3 | 15 | 0.3139 | 5.6298 | 4.1175 | OFF | OFF
4 | 20 | 0.4895 | 6.2874 | 3.1858 | OFF | OFF
5 | 25 | 0.6809 | 6.7167 | 2.5314 | OFF | OFF
6 | 30 | 0.8827 | 6.9984 | 2.044 | OFF | OFF
7 | 35 | 1.0913 | 7.178 | 1.6642 | OFF | OFF
8 | 40 | 1.303 | 7.2157 | 1.3593 | OFF | OFF
9 | 45 | 1.5191 | 7.3603 | 1.1635 | OFF | OFF
10 | 50 | 1.7361 | 7.3273 | 0.8801 | OFF | OFF
11 | 55 | 1.9514 | 7.2927 | 0.7356 | OFF | OFF
12 | 60 | 2.1653 | 7.2281 | 0.5937 | OFF | OFF
13 | 65 | 2.3768 | 7.139 | 0.4765 | OFF | OFF
14 | 70 | 2.5853 | 7.0299 | 0.3803 | OFF | OFF
15 | 75 | 2.7902 | 6.9046 | 0.3023 | OFF | OFF
16 | 80 | 2.9912 | 6.7666 | 0.2396 | OFF | OFF
17 | 85 | 3.1879 | 6.6184 | 0.1902 | OFF | OFF
18 | 90 | 3.3801 | 6.4627 | 0.1521 | OFF | OFF
19 | 95 | 3.5674 | 6.3014 | 0.1235 | OFF | OFF
20 | 100 | 3.7498 | 6.1363 | 0.1031 | OFF | OFF
21 | 105 | 3.9272 | 5.9688 | 0.0895 | OFF | OFF
22 | 110 | 4.0995 | 5.8003 | 0.0817 | OFF | OFF
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

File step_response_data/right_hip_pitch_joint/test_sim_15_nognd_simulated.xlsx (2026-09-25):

Index (số sample): | 281
Target Position: | 15
Sample | Time Step | Actual Angle | Actual RPM | Torque (Nm) | Obstacle | Ground
0 | 0 | 0.0006 | 0 | -0.0005 | OFF | OFF
1 | 5 | 0.0744 | 4.3624 | 10 | OFF | OFF
2 | 10 | 0.2445 | 6.9078 | 8.2963 | OFF | OFF
3 | 15 | 0.4723 | 8.4619 | 6.1636 | OFF | OFF
4 | 20 | 0.7364 | 9.4489 | 4.7641 | OFF | OFF
5 | 25 | 1.0242 | 10.0927 | 3.7815 | OFF | OFF
6 | 30 | 1.3277 | 10.5148 | 3.0498 | OFF | OFF
7 | 35 | 1.6414 | 10.7838 | 2.4799 | OFF | OFF
8 | 40 | 1.9614 | 10.9405 | 2.0223 | OFF | OFF
9 | 45 | 2.2856 | 11.0389 | 1.6478 | OFF | OFF
10 | 50 | 2.6106 | 11.0195 | 1.3159 | OFF | OFF
11 | 55 | 2.9344 | 10.9568 | 1.0759 | OFF | OFF
12 | 60 | 3.2558 | 10.8548 | 0.8709 | OFF | OFF
13 | 65 | 3.5736 | 10.719 | 0.6985 | OFF | OFF
14 | 70 | 3.8869 | 10.5544 | 0.5556 | OFF | OFF
15 | 75 | 4.1949 | 10.3663 | 0.4388 | OFF | OFF
16 | 80 | 4.4969 | 10.1592 | 0.3446 | OFF | OFF
17 | 85 | 4.7924 | 9.9371 | 0.2701 | OFF | OFF
18 | 90 | 5.0811 | 9.7035 | 0.2124 | OFF | OFF
19 | 95 | 5.3626 | 9.4616 | 0.1691 | OFF | OFF
20 | 100 | 5.6368 | 9.2138 | 0.1381 | OFF | OFF
21 | 105 | 5.9034 | 8.9626 | 0.1173 | OFF | OFF
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

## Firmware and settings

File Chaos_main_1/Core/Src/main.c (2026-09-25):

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
/* Includes ------------------------------------------------------------------*/
#include "main.h"

/* USER CODE BEGIN Includes */
#include "utils.h"
#include "NRF24.h"
#include "NRF24_reg_addresses.h"
/* USER CODE END Includes */

CAN_HandleTypeDef hcan2;

I2C_HandleTypeDef hi2c1;
I2C_HandleTypeDef hi2c2;

SPI_HandleTypeDef hspi1;
SPI_HandleTypeDef hspi3;
DMA_HandleTypeDef hdma_spi3_rx;
DMA_HandleTypeDef hdma_spi3_tx;

TIM_HandleTypeDef htim1;
TIM_HandleTypeDef htim2;
TIM_HandleTypeDef htim3;
TIM_HandleTypeDef htim4;
TIM_HandleTypeDef htim5;

/* USER CODE BEGIN PV */

volatile uint8_t init_ok;

/*  =========================== BQ76952 =========================== */
BQ76952_Data_t    bq76952       = {0};
BQ76952_Debug_t   bq_dbg        = {0};

/*  =========================== CAN / BQ error tracking =========================== */
uint32_t             err       = 0;
uint8_t              debug_i2c = 5;   /* set in debugger: 0-5, see BQ76952_DiagMode_t */
BQ76952_DiagResult_t bq_diag   = {0};

/*  =========================== NRF24L01 (RX / slave) =========================== */
static uint8_t nrf_addr[5] = {0x12, 0x34, 0x56, 0x78, 0x9A};  /* phai trung master */
static uint8_t nrf_buf[4];
float    nrf_vx = 0.0f, nrf_vy = 0.0f, nrf_vz = 0.0f;   /* gia tri nhan, [-0.5, 0.5] */
uint8_t  nrf_action = 0;                                 /* 0=block, 1=bat dau kiem tra arm */
uint32_t nrf_rx_count = 0;                               /* tong so goi nhan duoc */
uint32_t nrf_bad_width = 0;                              /* goi RX sai do dai */
uint32_t nrf_last_rx  = 0;                               /* tick cua goi cuoi */
uint8_t  nrf_link_ok  = 0;                               /* 1 = dang nhan, 0 = mat ket noi */

/* USER CODE END PV */

void SystemClock_Config(void);
static void MX_GPIO_Init(void);
static void MX_DMA_Init(void);
static void MX_I2C2_Init(void);
static void MX_SPI3_Init(void);
static void MX_CAN2_Init(void);
static void MX_I2C1_Init(void);
static void MX_TIM1_Init(void);
static void MX_TIM2_Init(void);
static void MX_TIM3_Init(void);
static void MX_TIM4_Init(void);
static void MX_SPI1_Init(void);
static void MX_TIM5_Init(void);
/* USER CODE BEGIN 0 */

/* Nạp ACK payload cho NRF: khi remote (master) gửi gói tới, NRF tự trả ACK kèm
 * 5 byte trạng thái này. Payload:
 *   [0] = init_done_mask bit 0..7
 *   [1] = init_done_mask bit 8..11
 *   [2] = rx_joints_received bit 0..7
 *   [3] = rx_joints_received bit 8..11
 *   [4] = flags: bit0 robot_falling (1=falling, 0=standing), bit1 all_nodes_ready
 * Phải nạp TRƯỚC khi gói tới (ack tự gửi bằng payload đang có trong FIFO).
 * LƯU Ý: remote (master) PHẢI bật Dynamic Payload + Ack Payload mới đọc được. */
static void nrf_load_status_ack(void)
{
    uint16_t init_mask = (uint16_t)(init_done_mask & 0x0FFFu);
    uint16_t rx_mask   = (uint16_t)(rx_joints_received & 0x0FFFu);
    uint8_t  buf[5];
    buf[0] = (uint8_t)(init_mask & 0xFF);
    buf[1] = (uint8_t)((init_mask >> 8) & 0x0F);
    buf[2] = (uint8_t)(rx_mask & 0xFF);
    buf[3] = (uint8_t)((rx_mask >> 8) & 0x0F);
    buf[4] = (uint8_t)((robot_falling ? 0x01u : 0x00u) |
                       (all_nodes_ready ? 0x02u : 0x00u));
    nrf24_flush_tx();                    /* ACK payload FIFO chi giu trang thai moi nhat */
    nrf24_transmit_rx_ack_pld(0, buf, 5);
}

/* USER CODE END 0 */

/**
  * @brief  The application entry point.
  * @retval int
  */
int main(void)
{

  /* MCU Configuration--------------------------------------------------------*/

  /* Reset of all peripherals, Initializes the Flash interface and the Systick. */
  HAL_Init();

  /* Configure the system clock */
  SystemClock_Config();

  /* Initialize all configured peripherals */
  MX_GPIO_Init();
  MX_DMA_Init();
  MX_I2C2_Init();
  MX_SPI3_Init();
  MX_CAN2_Init();
  MX_I2C1_Init();
  MX_TIM1_Init();
  MX_TIM2_Init();
  MX_TIM3_Init();
  MX_TIM4_Init();
  MX_SPI1_Init();
  MX_TIM5_Init();
  /* USER CODE BEGIN 2 */

  /*  =========================== MPU6050 Init =========================== */
  HAL_Delay(200);
  MPU6050_Init(&mpu, &hi2c1);
  MPU6050_Calibrate(&mpu);
  MPU6050_Update(&mpu);       /* Prime IMU outputs for debugger/first obs frame. */
  init_ok = 1;
  HAL_Delay(500);

  /*  =========================== BQ76952 Init =========================== */
  HAL_GPIO_WritePin(BQ_RST_SHUNT_PORT, BQ_RST_SHUNT_PIN, GPIO_PIN_RESET);
  HAL_Delay(100);

  bq76952.hi2c = &hi2c2;
  BQ76952_Diagnose(&bq76952, (BQ76952_DiagMode_t)debug_i2c,
                   GPIOB, GPIO_PIN_10, &bq_diag);

  if (bq_diag.i2c_status == HAL_OK)
  {
      BQ76952_SendSubcommand(&bq76952, BQ_SUBCMD_RESET);
      HAL_Delay(1000);

      BQ76952_Status_t init_ret = BQ76952_Init(&hi2c2, &bq76952, &bq_dbg);
      bq_dbg.cfg_ok = (init_ret == BQ_OK) ? 1 : 0;

      if (init_ret == BQ_OK)
      {
          BQ76952_DisableAllProtections(&bq76952);
          BQ76952_AllFetsOn(&bq76952);
          BQ76952_VerifyConfig(&bq76952, &bq_dbg);
          BQ76952_ReadAllData(&bq76952);
          BQ76952_UpdateDebug(&bq76952, &bq_dbg);
          HAL_GPIO_WritePin(LED_PORT, LED_L2, GPIO_PIN_SET);   /* L2: BMS OK        */
      }
      else
          HAL_GPIO_WritePin(LED_PORT, LED_L4, GPIO_PIN_SET);   /* L4: config error  */
  }
  else
      HAL_GPIO_WritePin(LED_PORT, LED_L4, GPIO_PIN_SET);       /* L4: not found     */

  HAL_Delay(50);

  /*  =========================== Jetson Output Pin Init =========================== */
  HAL_GPIO_WritePin(JETSON_OUT_PORT, JETSON_OUT_PIN, GPIO_PIN_RESET);
  jetson_out = 0;

  /*  =========================== Protection Init =========================== */
  /* Khởi tạo trạng thái có nhớ TRƯỚC khi start SPI/CAN (callback có thể chạy
   * ngay sau đó). Lớp NaN/range không cần init; slew/watchdog/stats cần.      */
  Protection_StatsReset(&prot_stats);
  Protection_SlewInit(&action_slew, PROT_ACTION_SLEW_MAX);
  Protection_WatchdogInit(&jetson_action_wd, PROT_ACTION_TIMEOUT_MS);
  jetson_action_link_ok = 0;

  /* Obs thiếu-khớp policy */
  obs_locked      = 0;
  obs_bad_streak  = 0;
  obs_good_streak = 0;

  /* Falling detection */
  robot_falling   = 0;

  /* Arming: chưa cho xuất action tới khi obs+action ổn định 5s (init/đứng dậy) */
  action_armed    = 0;

  /*  =========================== SPI3 DMA Start =========================== */
  HAL_SPI_TransmitReceive_DMA(&hspi3,
      (uint8_t *)spi_tx_buffer,
      (uint8_t *)spi_rx_buffer,
      SPI_PAYLOAD_FLOATS * sizeof(float));

  /*  =========================== CAN2 Filter & Start =========================== */
  CAN_FilterTypeDef filter = {0};
  filter.FilterActivation      = ENABLE;
  filter.FilterBank            = 14;
  filter.SlaveStartFilterBank  = 14;
  filter.FilterFIFOAssignment  = CAN_FILTER_FIFO0;
  filter.FilterMode            = CAN_FILTERMODE_IDMASK;
  filter.FilterScale           = CAN_FILTERSCALE_32BIT;
  filter.FilterIdHigh          = 0x0000;
  filter.FilterIdLow           = 0x0000;
  filter.FilterMaskIdHigh      = 0x0000;
  filter.FilterMaskIdLow       = 0x0000;

  if (HAL_CAN_ConfigFilter(&hcan2, &filter) != HAL_OK) Error_Handler();
  if (HAL_CAN_ActivateNotification(&hcan2,
        CAN_IT_RX_FIFO0_MSG_PENDING |
        CAN_IT_TX_MAILBOX_EMPTY     |
        CAN_IT_ERROR                |
        CAN_IT_BUSOFF               |
        CAN_IT_LAST_ERROR_CODE      |
        CAN_IT_ERROR_WARNING        |
        CAN_IT_ERROR_PASSIVE) != HAL_OK) Error_Handler();
  if (HAL_CAN_Start(&hcan2) != HAL_OK) Error_Handler();

  err = HAL_CAN_GetError(&hcan2);

  /*  =========================== Init-done handshake ===========================
   * Hỏi 12 node đã homing/init xong chưa. TIM5 broadcast CHECK_INIT_DONE mỗi 5s
   * tới khi gom đủ 12 bit (init_done_mask == INIT_DONE_ALL_MASK). Chỉ khi đủ
   * (all_nodes_ready = 1) thì EXTI/SPI mới cho phép chu kỳ điều khiển với Jetson.
   * Node báo bằng CAN_ID_INIT_DONE = 101..112; CAN RX callback set bit + stop TIM5. */
  init_done_mask  = 0;
  all_nodes_ready = 0;
  CAN_SendCheckInitDone();              /* hỏi ngay lần đầu, không chờ 5s        */
  HAL_TIM_Base_Start_IT(&htim5);

  /*  =========================== NRF24L01 setup as RX =========================== */
  /* CSN=PA4, CE=PC5 (da cau hinh GPIO output trong MX_GPIO_Init). SPI1 master, /16. */
  nrf24_defaults();
  HAL_Delay(5);
  nrf24_init();

  nrf24_open_tx_pipe(nrf_addr);            /* auto-ack: TX addr = pipe0 addr */
  nrf24_open_rx_pipe(0, nrf_addr);
  nrf24_pipe_pld_size(0, 4);               /* 4 byte: vx, vy, vz, action */
  nrf24_set_channel(110);     /* phai trung master */
  nrf24_data_rate(_1mbps);    /* phai trung master (TEST 1Mbps) */
  nrf24_tx_pwr(_0dbm);
  nrf24_set_crc(en_crc, _1byte);
  nrf24_auto_ack(0, enable);
  /* Dynamic payload + ACK payload: cho phép NRF trả trạng thái về remote qua ACK.
   * (Remote/master PHẢI bật DPL + ack-payload tương ứng mới nhận được.)        */
  nrf24_activate_features();
  nrf24_dpl(enable);
  nrf24_set_rx_dpl(0, enable);
  nrf24_en_ack_pld(enable);
  nrf24_listen();                           /* vao che do RX, CE len HIGH */
  nrf_load_status_ack();                    /* nạp ACK payload lần đầu          */

  /* TIM2/3/4 are started on-demand from ISR callbacks — not at boot */

#if TEST
  HAL_TIM_Base_Start_IT(&htim1);
#endif

  /* USER CODE END 2 */

  spi_last_ms = HAL_GetTick();   /* mốc khởi điểm cho watchdog SPI */
  uint8_t spi_link_lost = 0;     /* cạnh: đã kích xử lý mất-SPI chưa */

  /* Infinite loop */
  /* USER CODE BEGIN WHILE */
  while (1)
  {
    /* USER CODE END WHILE */

    /* USER CODE BEGIN 3 */
    for (uint8_t nrf_drain = 0; nrf_drain < 3 && nrf24_data_available(); nrf_drain++)
    {
      uint8_t pld_width = nrf24_r_pld_wid();
      if (pld_width != 4)
      {
        nrf24_flush_rx();
        nrf24_clear_rx_dr();
        nrf_bad_width++;
        nrf_load_status_ack();
        continue;
      }

      nrf24_receive(nrf_buf, 4);

      /* moi byte = int8 co dau = gia tri*100 -> chia 100 lai.
       * Ghi THẲNG vào vel_cmd[0..2] (vx,vy,vyaw) -> obs SPI_IDX_CMD lên Jetson. */
      vel_cmd[0] = (float)((int8_t)nrf_buf[0]) / 100.0f;   /* vx   -0.5..+0.5 */
      vel_cmd[1] = (float)((int8_t)nrf_buf[1]) / 100.0f;   /* vy             */
      vel_cmd[2] = (float)((int8_t)nrf_buf[2]) / 100.0f;   /* vyaw           */
      nrf_vx = vel_cmd[0]; nrf_vy = vel_cmd[1]; nrf_vz = vel_cmd[2]; /* mirror debug */
      nrf_action = nrf_buf[3] ? 1 : 0;

      nrf_rx_count++;
      nrf_last_rx = HAL_GetTick();

      /* Nạp lại ACK payload mới nhất cho lần ACK kế tiếp. */
      nrf_load_status_ack();
    }

    /* mat ket noi neu qua 500ms khong co goi moi */
    nrf_link_ok = ((HAL_GetTick() - nrf_last_rx) < 500) ? 1 : 0;

    /* ===== Watchdog SPI: Jetson không clock SPI quá lâu -> mất link =====
     * -> về "chưa init" (STATUS=WAIT cho Jetson) + broadcast CAN 150 cho node homing.
     * Cạnh-kích: chỉ xử lý 1 lần mỗi lần mất; SPI sống lại thì re-arm. */
    if ((uint32_t)(HAL_GetTick() - spi_last_ms) > SPI_TIMEOUT_MS)
    {
      if (!spi_link_lost)
      {
        spi_link_lost   = 1;
        all_nodes_ready = 0;          /* chưa sẵn sàng -> STATUS=WAIT, chặn action */
        init_done_mask  = 0;
        action_armed    = 0;
        CAN_SendFalling();            /* gửi 150 cho node homing (3 lần cho chắc) */
        CAN_SendFalling();
        CAN_SendFalling();
        HAL_TIM_Base_Start_IT(&htim5);  /* poll lại CHECK_INIT_DONE */
      }
    }
    else
    {
      spi_link_lost = 0;
    }

    /* Protection: giam sat link action tu Jetson (watchdog, Lop 5).
     * CHI danh gia khi dang RUN — luc HOLD ta co tinh khong forward action nen
     * watchdog khong duoc feed, khong tinh la "mat link" (tranh dem nham).     */
    if (Robot_SafeLevel() == SAFE_RUN)
    {
      uint8_t link_ok = !Protection_WatchdogExpired(&jetson_action_wd, HAL_GetTick());
      if (!link_ok && jetson_action_link_ok)
      {
          prot_stats.stale_events++;     /* canh xuong: vua mat lenh           */
          dbg_action_timeout_ms = HAL_GetTick();
      }
      jetson_action_link_ok = link_ok;
    }
    else
    {
      jetson_action_link_ok = 0;         /* dang HOLD: link coi nhu chua active */
    }
  }
  /* USER CODE END 3 */
}

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


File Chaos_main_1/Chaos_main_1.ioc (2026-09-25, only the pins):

Mcu.UserName=STM32F407VETx
PA13.Signal=SYS_JTMS-SWDIO
PA14.Signal=SYS_JTCK-SWCLK
PA15.Signal=SPI3_NSS
PA4.Signal=GPIO_Output
PA5.Signal=SPI1_SCK
PA6.Signal=SPI1_MISO
PA7.Signal=SPI1_MOSI
PA8.Signal=GPXTI8
PB10.Signal=I2C2_SCL
PB11.Signal=I2C2_SDA
PB12.Signal=CAN2_RX
PB13.Signal=CAN2_TX
PB6.Signal=I2C1_SCL
PB7.Signal=I2C1_SDA
PC1.Signal=GPIO_Output
PC10.Signal=SPI3_SCK
PC11.Signal=SPI3_MISO
PC12.Signal=SPI3_MOSI
PC2.Signal=GPIO_Output
PC5.Signal=GPIO_Output
PC9.Signal=GPIO_Output
PD5.Signal=GPIO_Output
PD6.Signal=GPXTI6
PE2.Signal=GPIO_Output
PE3.Signal=GPIO_Output
PE4.Signal=GPIO_Output
PE5.Signal=GPIO_Output
PH0-OSC_IN.Signal=RCC_OSC_IN
PH1-OSC_OUT.Signal=RCC_OSC_OUT

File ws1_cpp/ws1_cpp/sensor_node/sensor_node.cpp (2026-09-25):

#include "sensor_node.hpp"

#include <fcntl.h>
#include <unistd.h>
#include <cstdint>
#include <sys/ioctl.h>
#include <linux/spi/spidev.h>
#include <cstring>
#include <iostream>
#include <chrono>
#include <cmath>

#include <std_msgs/msg/float32_multi_array.hpp>

static constexpr unsigned int GPIO_CHIP_NUM    = 0;
static constexpr unsigned int GPIO_PIN15_LINE  = 85;    // OUTPUT – GPIO12 (header pin 15), 50Hz toggle
static constexpr unsigned int GPIO_PIN7_LINE   = 144;   // INPUT  – GPIO09 (header pin 7), EXTI rising edge

#define TEST 0

#if TEST == 2

// ══════════════════════════════════════════════════════════════════════════════
// TEST MODE 2: SPI loopback test at 5Hz, no GPIO, print received data
// ══════════════════════════════════════════════════════════════════════════════

SensorNode::SensorNode()
: Node("sensor_node"),
  spi_fd_(-1),
  spi_device_("/dev/spidev0.0"),
  spi_speed_(1000000),
  spi_mode_(SPI_MODE_0),
  bits_per_word_(8),
  num_floats_(45),
  rx_len_(num_floats_ * sizeof(float)),
  gpio_chip_(nullptr),
  line_trig_(nullptr),
  line_exti_(nullptr)
{
    if (!openSPI()) throw std::runtime_error("Failed to open SPI");

    timer_ = this->create_wall_timer(
        std::chrono::milliseconds(200),
        std::bind(&SensorNode::timerCallback, this));

    RCLCPP_INFO(this->get_logger(),
        "[TEST2] SPI-only mode | 5Hz transfer | print RX data");
}

SensorNode::~SensorNode()
{
    closeSPI();
}

void SensorNode::timerCallback()
{
    static uint32_t cycle = 0;
    cycle++;

    std::vector<uint8_t> tx(rx_len_, 0);
    std::vector<uint8_t> rx(rx_len_, 0);

    std::vector<float> tx_floats(num_floats_);
    for (int i = 0; i < num_floats_; i++) {
        tx_floats[i] = (float)cycle + i * 0.01f;
    }
    memcpy(tx.data(), tx_floats.data(), rx_len_);

    struct spi_ioc_transfer tr{};
    memset(&tr, 0, sizeof(tr));
    tr.tx_buf        = reinterpret_cast<__u64>(tx.data());
    tr.rx_buf        = reinterpret_cast<__u64>(rx.data());
    tr.len           = rx_len_;
    tr.speed_hz      = spi_speed_;
    tr.bits_per_word = bits_per_word_;

    int ret = ioctl(spi_fd_, SPI_IOC_MESSAGE(1), &tr);

    if (ret != (int)rx_len_) {
        RCLCPP_ERROR(this->get_logger(),
            "[TEST2][SPI] Transfer FAILED! Expected %d bytes, got %d", rx_len_, ret);
        return;
    }

    std::vector<float> rx_floats(num_floats_);
    memcpy(rx_floats.data(), rx.data(), rx_len_);

    RCLCPP_INFO(this->get_logger(),
        "[TEST2][SPI] Cycle %u | TX[0]=%.2f TX[1]=%.2f | RX[0]=%.2f RX[1]=%.2f RX[2]=%.2f",
        cycle,
        tx_floats[0], tx_floats[1],
        rx_floats[0], rx_floats[1], rx_floats[2]);

    for (int i = 0; i < num_floats_; i++) {
        RCLCPP_INFO(this->get_logger(),
            "[TEST2][SPI]   RX[%2d] = %.6f", i, rx_floats[i]);
    }
}

// Stubs — GPIO not used in TEST 2
bool SensorNode::openGPIO()  { return true; }
void SensorNode::closeGPIO() {}
void SensorNode::gpioWatchThread() {}
void SensorNode::doSPITransfer() {}

bool SensorNode::openSPI()
{
    spi_fd_ = open(spi_device_.c_str(), O_RDWR);
    if (spi_fd_ < 0) { perror("SPI open"); return false; }

    if (ioctl(spi_fd_, SPI_IOC_WR_MODE, &spi_mode_) < 0)
        { perror("SPI mode"); return false; }
    if (ioctl(spi_fd_, SPI_IOC_WR_BITS_PER_WORD, &bits_per_word_) < 0)
        { perror("SPI bits"); return false; }
    if (ioctl(spi_fd_, SPI_IOC_WR_MAX_SPEED_HZ, &spi_speed_) < 0)
        { perror("SPI speed"); return false; }

    RCLCPP_INFO(rclcpp::get_logger("sensor_node"),
        "[TEST2] SPI opened: %s @ %d Hz", spi_device_.c_str(), spi_speed_);
    return true;
}

void SensorNode::closeSPI()
{
    if (spi_fd_ >= 0) { close(spi_fd_); spi_fd_ = -1; }
}

int main(int argc, char **argv)
{
    rclcpp::init(argc, argv);
    rclcpp::spin(std::make_shared<SensorNode>());
    rclcpp::shutdown();
    return 0;
}

#elif TEST == 1

// ══════════════════════════════════════════════════════════════════════════════
// TEST MODE 1: GPIO + SPI
//   - Pin 15 pulses HIGH every 20ms (50 Hz)
//   - Pin 7 rising edge → pull pin 15 LOW, then do SPI transfer
//   - TX always sends all 1.0f
//   - Prints dt between consecutive rising edges + latency from pin15 HIGH
// ══════════════════════════════════════════════════════════════════════════════

SensorNode::SensorNode()
: Node("sensor_node"),
  spi_fd_(-1),
  spi_device_("/dev/spidev0.0"),
  spi_speed_(1000000),
  spi_mode_(SPI_MODE_0),
  bits_per_word_(8),
  num_floats_(45),
  rx_len_(num_floats_ * sizeof(float)),
  gpio_chip_(nullptr),
  line_trig_(nullptr),
  line_exti_(nullptr)
{
    if (!openSPI())  throw std::runtime_error("Failed to open SPI");
    if (!openGPIO()) throw std::runtime_error("Failed to open GPIO");

    timer_ = this->create_wall_timer(
        std::chrono::milliseconds(10),
        std::bind(&SensorNode::timerCallback, this));

    RCLCPP_INFO(this->get_logger(),
        "[TEST1] GPIO+SPI mode | pin15=50Hz pulse | pin7=EXTI→SPI | TX=all 1.0");
}

SensorNode::~SensorNode()
{
    closeGPIO();
    closeSPI();
}

bool SensorNode::openGPIO()
{
    std::string chip_path = "/dev/gpiochip" + std::to_string(GPIO_CHIP_NUM);
    gpio_chip_ = gpiod_chip_open(chip_path.c_str());
    if (!gpio_chip_) { perror("gpiod_chip_open"); return false; }

    line_trig_ = gpiod_chip_get_line(gpio_chip_, GPIO_PIN15_LINE);
    if (!line_trig_) { perror("gpiod_chip_get_line(trig)"); return false; }
    if (gpiod_line_request_output(line_trig_, "sensor_node_trig", 0) < 0) {
        perror("gpiod_line_request_output"); return false;
    }

    line_exti_ = gpiod_chip_get_line(gpio_chip_, GPIO_PIN7_LINE);
    if (!line_exti_) { perror("gpiod_chip_get_line(exti)"); return false; }
    if (gpiod_line_request_rising_edge_events(line_exti_, "sensor_node_exti") < 0) {
        perror("gpiod_line_request_rising_edge_events"); return false;
    }

    gpio_thread_run_.store(true);
    gpio_thread_ = std::thread(&SensorNode::gpioWatchThread, this);

    return true;
}

void SensorNode::closeGPIO()
{
    gpio_thread_run_.store(false);
    if (gpio_thread_.joinable()) gpio_thread_.join();

    if (line_trig_) { gpiod_line_release(line_trig_); line_trig_ = nullptr; }
    if (line_exti_) { gpiod_line_release(line_exti_); line_exti_ = nullptr; }
    if (gpio_chip_) { gpiod_chip_close(gpio_chip_);   gpio_chip_ = nullptr; }
}
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

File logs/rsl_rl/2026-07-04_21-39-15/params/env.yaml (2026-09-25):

viewer:
  eye: !!python/tuple
  - 8.0
  - 0.0
  - 5.0
  lookat: !!python/tuple
  - 0.0
  - 0.0
  - 0.0
  cam_prim_path: /OmniverseKit_Persp
  resolution: !!python/tuple
  - 1280
  - 720
  origin_type: world
  env_index: 0
  asset_name: null
  body_name: null
sim:
  physics_prim_path: /physicsScene
  device: cuda:0
  dt: 0.005
  render_interval: 4
  gravity: !!python/tuple
  - 0.0
  - 0.0
  - -9.81
  enable_scene_query_support: false
  use_fabric: true
  physx:
    solver_type: 1
    solve_articulation_contact_last: false
    min_position_iteration_count: 1
    max_position_iteration_count: 255
    min_velocity_iteration_count: 0
    max_velocity_iteration_count: 255
    enable_ccd: false
    enable_stabilization: false
    enable_external_forces_every_iteration: false
    enable_enhanced_determinism: false
    bounce_threshold_velocity: 0.5
    friction_offset_threshold: 0.04
    friction_correlation_distance: 0.025
    gpu_max_rigid_contact_count: 8388608
    gpu_max_rigid_patch_count: 163840
    gpu_found_lost_pairs_capacity: 2097152
    gpu_found_lost_aggregate_pairs_capacity: 33554432
    gpu_total_aggregate_pairs_capacity: 2097152
    gpu_collision_stack_size: 67108864
    gpu_heap_capacity: 67108864
    gpu_temp_buffer_capacity: 16777216
    gpu_max_num_partitions: 8
    gpu_max_soft_body_contacts: 1048576
    gpu_max_particle_contacts: 1048576
  physics_material:
    func: isaaclab.sim.spawners.materials.physics_materials:spawn_rigid_body_material
    static_friction: 0.5
    dynamic_friction: 0.5
    restitution: 0.0
    friction_combine_mode: average
    restitution_combine_mode: average
    compliant_contact_stiffness: 0.0
    compliant_contact_damping: 0.0
  render:
    enable_translucency: null
    enable_reflections: null
    enable_global_illumination: null
    antialiasing_mode: null
    enable_dlssg: null
    enable_dl_denoiser: null
    dlss_mode: null
    enable_direct_lighting: null
    samples_per_pixel: null
    enable_shadows: null
    enable_ambient_occlusion: null
    dome_light_upper_lower_strategy: null
    carb_settings: null
    rendering_mode: null
  create_stage_in_memory: false
  logging_level: WARNING
  save_logs_to_file: true
  log_dir: null
ui_window_class_type: isaaclab.envs.ui.manager_based_rl_env_window:ManagerBasedRLEnvWindow
seed: 42
decimation: 4
scene:
  num_envs: 2048
  env_spacing: 4.0
  lazy_sensor_update: true
  replicate_physics: true
  filter_collisions: true
  clone_in_fabric: false
  robot:
    class_type: isaaclab.assets.articulation.articulation:Articulation
    prim_path: /World/envs/env_.*/Robot
    spawn:
      func: isaaclab.sim.spawners.from_files.from_files:spawn_from_usd
      visible: true
      semantic_tags: null
      copy_from_source: true
      mass_props: null
      deformable_props: null
      rigid_props:
        rigid_body_enabled: true
        kinematic_enabled: null
        disable_gravity: false
        linear_damping: 0.0
        angular_damping: 0.0
        max_linear_velocity: 1000.0
        max_angular_velocity: 1000.0
        max_depenetration_velocity: 1.0
        max_contact_impulse: null
        enable_gyroscopic_forces: null
        retain_accelerations: false
        solver_position_iteration_count: null
        solver_velocity_iteration_count: null
        sleep_threshold: null
        stabilization_threshold: null
      collision_props: null
      activate_contact_sensors: true
      scale: null
      articulation_props:
        articulation_enabled: null
        enabled_self_collisions: true
        solver_position_iteration_count: 8
        solver_velocity_iteration_count: 1
        sleep_threshold: null
        stabilization_threshold: null
        fix_root_link: null
      fixed_tendons_props: null
      spatial_tendons_props: null
      joint_drive_props: null
      visual_material_path: material
      visual_material: null
      usd_path: D:/IsaacSim/test7.usd
      variants: null
    init_state:
      pos: !!python/tuple
      - 0.0
      - 0.0
      - 0.5852
      rot: !!python/tuple
      - 1.0
      - 0.0
      - 0.0
      - 0.0
      lin_vel: !!python/tuple
      - 0.0
      - 0.0
      - 0.0
      ang_vel: !!python/tuple
      - 0.0
      - 0.0
      - 0.0
      joint_pos:
        right_hip_pitch_joint: 0.1
        right_knee_joint: 0.2
        right_ankle_pitch_joint: 0.1
        left_hip_pitch_joint: 0.1
        left_knee_joint: 0.2
        left_ankle_pitch_joint: 0.1
      joint_vel:
        .*: 0.0
    collision_group: -1
    debug_vis: false
    articulation_root_prim_path: null
    soft_joint_pos_limit_factor: 0.9
    actuators:
      hip_pitch:
        class_type: isaaclab.actuators.actuator_pd:ImplicitActuator
        joint_names_expr:
        - .*_hip_pitch_joint
        effort_limit: 10.0
        velocity_limit: 14.653
        effort_limit_sim: 10.0
        velocity_limit_sim: 14.653
        stiffness: 45.0
        damping: 7.5
        armature: 0.0
        friction: 1.0
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
